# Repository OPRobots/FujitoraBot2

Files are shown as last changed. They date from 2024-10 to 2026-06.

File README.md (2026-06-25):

# FujitoraBot2

Versión 2 de FujitoraBot renovando el hardware después de 5 años: un pelín más
rápido, con 24 sensores de línea, giroscopio MPU-6500 y diseño más modular.

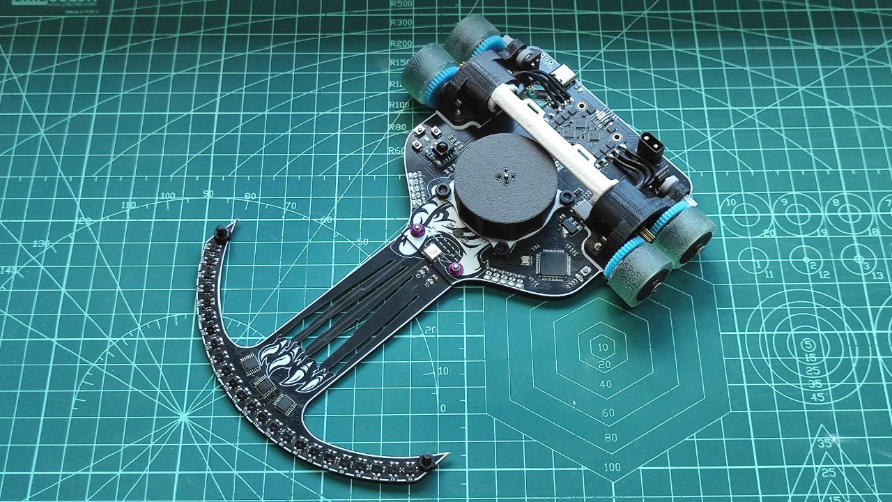
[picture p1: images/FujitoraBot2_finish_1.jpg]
FujitoraBot2


## 🏆 Palmarés

| Competición | Resultado | Fecha |
|---|---|---|
| — | — | — |

## ⚙️ Hardware

| Componente | Detalle |
|---|---|
| **Microcontrolador** | STM32F405RGT6 @ 168 MHz, Cortex-M4F |
| **Sensores** | 24× IR de línea (multiplexados 3×8:1), MPU-6500 (giro ±2000 dps, SPI) |
| **Motores** | 2× DC brushless con ESC BLHeli (OneShot125) |
| **Encoders** | 2× magnéticos en cuadratura (TIM3/TIM4) |
| **Batería** | LiPo 2S/3S, detección automática, divisor ×3.8673 |
| **Ventilador** | Control PWM independiente con rampa de aceleración |
| **Chasis** | PCB propia (KiCad) + impresión 3D |
| **Peso** | — |

## 💻 Software

| Componente | Detalle |
|---|---|
| **Framework** | LibOpenCM3 |
| **Entorno** | PlatformIO |
| **Lenguaje** | C11 |
| **Frecuencia control** | 1000 Hz (TIM5) |
| **Algoritmo** | PID en cascada (velocidad + ángulo + sensores de línea) |
| **Odometría** | Encoders + giroscopio, integración de posición X/Y/θ |
| **Debug** | USART3 @ 115200 + MacroArray (30k registros de telemetría) |

## 📚 Documentación

La documentación técnica completa está en [docs/](docs/):

- [Hardware](docs/01-hardware.md) — MCU, pinout, sensores, actuadores, chasis
- [Arquitectura Software](docs/02-software-architecture.md) — ISRs, DMA, prioridades, flujo
- [Sensores](docs/03-sensors.md) — 24 IR multiplexados, MPU-6500, filtros
- [Movimiento](docs/04-movement.md) — Motores BLHeli, OneShot125, ventilador
- [Control PID](docs/05-control-system.md) — PID cascada, ant-windup, arranque
- [Menú](docs/06-menu-system.md) — Navegación, perfiles, calibración/debug
- [Debug](docs/07-debug-system.md) — USART, macroarray, modos de diagnóstico
- [Calibración](docs/08-calibration.md) — Giroscopio Z, sensores IR, EEPROM
- [EEPROM](docs/09-storage.md) — Flash sector 11, layout de datos
- [Encoders y Giroscopio](docs/10-encoders-gyro.md) — Odometría, MPU-6500, fusión
- [Batería y LEDs](docs/11-battery-leds.md) — Medición, 2S/3S, indicadores
- [Cinemática](docs/12-kinematics.md) — 6 perfiles de velocidad predefinidos
- [Problemas Conocidos](docs/13-known-issues.md) — Issues y bugs documentados

## 🎥 Vídeos

<!-- Enlaces a vídeos del robot en acción -->

## 🔧 Stack Tecnológico

| Herramienta | Tecnología |
|---|---|
| **Microcontrolador** | STM32F405RGT6 |
| **Framework** | LibOpenCM3 |
| **IDE / Build** | PlatformIO |
| **Lenguaje** | C11 |
| **PCB** | KiCad |
| **3D** | SketchUp + STL |

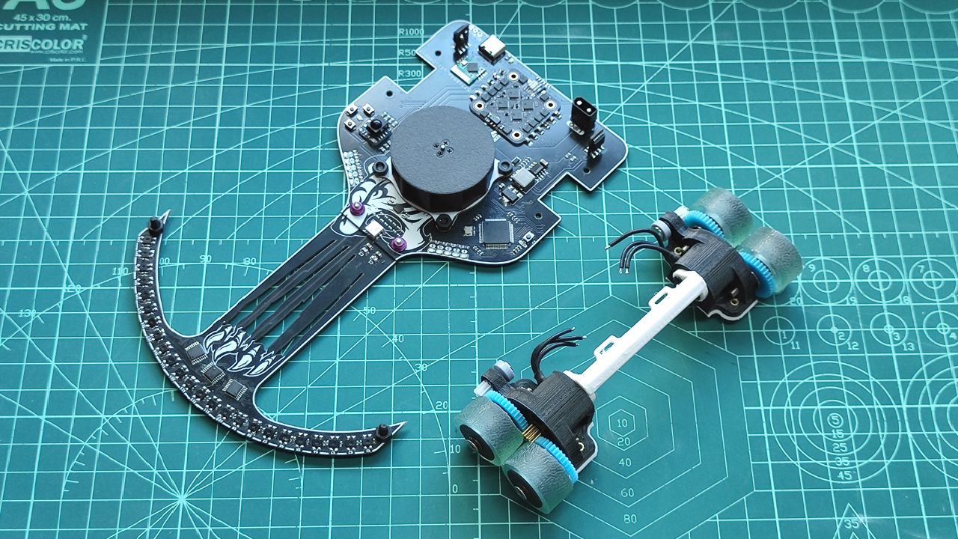
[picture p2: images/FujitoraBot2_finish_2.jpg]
FujitoraBot2


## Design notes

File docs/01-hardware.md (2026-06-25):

# Hardware

## Microcontrolador

| Característica | Detalle |
|---|---|
| **Modelo** | STM32F405RGT6 |
| **Arquitectura** | ARM Cortex-M4F |
| **Frecuencia** | 168 MHz (SYSCLK) |
| **Flash** | 1024 KB |
| **RAM** | 192 KB |
| **Encapsulado** | LQFP-64 |

El reloj principal se genera a partir del HSE de 8 MHz con PLL hasta 168 MHz
([`setup.c:15`](../source_code/src/setup.c#L15)).

## Placa base

Diseño propio en KiCad con dos variantes:

- **Main** — placa principal con MCU, drivers de motor, MPU, y conectores
- **Sensors 24** — placa frontal con 24 sensores IR y multiplexores

Ambos diseños están disponibles en [`pcb_files/kicad_project/`](../pcb_files/kicad_project/).

## Pinout

### GPIOA

| Pin | Función | AF | Descripción |
|-----|---|----|---|
| PA0–PA7 | GPIO Output | — | LEDs de info (menú) |
| PA8–PA11 | AF1 (TIM1) | 1 | PWM LEDs RGB |
| PA15 | GPIO Output | — | CS del MPU (NSS software) |

### GPIOB

| Pin | Función | AF | Descripción |
|-----|---|----|---|
| PB4–PB7 | AF2 (TIM3/4) | 2 | Encoders en cuadratura |
| PB10–PB11 | AF7 (USART3) | 7 | UART debug |
| PB12–PB15 | GPIO Input | — | Botones de menú + IR start |

### GPIOC

| Pin | Función | AF | Descripción |
|-----|---|----|---|
| PC0–PC3 | ADC1 (IN10–IN12) | — | Sensores de línea (3 canales ADC) |
| PC4–PC5 | GPIO Output | — | LEDs de info adicionales |
| PC6–PC9 | AF3 (TIM8) | 3 | PWM motores + ventilador |
| PC10–PC12 | AF6 (SPI3) | 6 | SPI para MPU-6500 |
| PC13–PC15 | GPIO Output | — | Multiplexor de sensores (A/B/C) |

## Sensores

| Característica | Detalle |
|---|---|
| **Sensores de línea** | 24 pares IR (emisor + fototransistor) |
| **Multiplexado** | 3× multiplexores 8:1 → 3 canales ADC (PC0/PC1/PC2) |
| **Giroscopio** | MPU-6500 vía SPI3, ±2000 dps |

(ver [Sensores](03-sensors.md))

## Actuadores

| Componente | Control | Detalle |
|---|---|---|
| **Motor izquierdo** | TIM8 CH1 (PC6) | PWM OneShot125, ESC BLHeli |
| **Motor derecho** | TIM8 CH3 (PC8) | PWM OneShot125, ESC BLHeli |
| **Ventilador** | TIM8 CH2+CH4 (PC7+PC9) | PWM, velocidad configurable por perfil |

(ver [Movimiento](04-movement.md))

## Alimentación

| Característica | Detalle |
|---|---|
| **Batería** | LiPo 2S (7.4 V) o 3S (11.1 V) |
| **Detección** | Automática por rango de tensión |
| **Medición** | ADC2 (PC3/IN13) con divisor ×3.8673 |
| **Límites** | 2S: 7.4–8.2 V / 3S: 11.1–12.6 V |

(ver [Batería y LEDs](11-battery-leds.md))

## Chasis

| Componente | Material | Diseño |
|---|---|---|
| **Chasis principal** | Impresión 3D & PCB | [`3d_model/stl_files/`](../3d_model/stl_files/) |
| **Soporte sensores** | PCB dedicada (sensors_24) | [`pcb_files/kicad_project/sensors_24/`](../pcb_files/kicad_project/sensors_24/) |
| **Ruedas** | — | Control diferencial, separación 0.12 m |

---

*Documento generado el 2026-06-25. Ver también [Arquitectura Software](02-software-architecture.md), [Sensores](03-sensors.md).*

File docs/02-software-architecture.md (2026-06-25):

# Arquitectura Software

## Visión general

El firmware de FujitoraBot2 corre sobre STM32F405RGT6 con LibOpenCM3. Sigue un
modelo baremetal con interrupciones jerarquizadas: el SysTick a 1 kHz orquesta
las lecturas de sensores y encoders, mientras que un timer de alta prioridad
(TIM5) ejecuta el lazo de control a 1 kHz.

## Flujo principal

```mermaid
flowchart TD
    A[main] --> B[setup]
    B --> C[show_battery_level]
    C --> D[eeprom_load]
    D --> E[sensors_calibration]
    E --> F{race_started?}
    F -->|No| G[menu_handler]
    G --> H{check_start_run?}
    H -->|Sí| I[Configurar cinemática]
    I --> J[Cuenta atrás + fade RGB]
    J --> K[Arrancar motores]
    K --> F
    H -->|No| F
    F -->|Sí| L{IR start off?}
    L -->|Sí| M[emergency_stop]
    L -->|No| F
```

## Mapa de interrupciones

| IRQ | Prioridad | Handler | Función |
|-----|---|---|---|
| **SysTick** | 0 (máx) | `sys_tick_handler` | Clock tick, encoders, ESC init, botones, sensores, giro, batería |
| **DMA2 Stream0** | 1 | `dma2_stream0_isr` | Lectura DMA de ADC1 → actualización multiplexor |
| **TIM2** | 2 | — | Captura encoder derecho |
| **TIM5** | 3 | `tim5_isr` | Lazo de control PID @ 1 kHz |
| **USART3** | 4 | — | Recepción UART (no crítica) |

Las prioridades están definidas en [`setup.c:52-63`](../source_code/src/setup.c#L52-L63).
La prioridad 0 es la más alta en el esquema NVIC de Cortex-M4 (16 grupos).

## SysTick (1 kHz)

El `sys_tick_handler` en [`main.c:19-27`](../source_code/src/main.c#L19-L27) ejecuta
cada milisegundo:

1. `clock_tick()` — incrementa el contador de tiempo del sistema
2. `update_encoder_readings()` — lee encoders en cuadratura y calcula odometría
3. `init_esc()` — secuencia de inicialización de los ESCs (5 s de pulso neutro)
4. `check_buttons()` — lee los botones físicos
5. `sensors_update_line_position()` — calcula la posición de la línea
6. `update_gyro_readings()` — lee el giroscopio y actualiza el ángulo integrado
7. `update_battery_voltage()` — lee y filtra la tensión de batería

## Lazo de control (TIM5, ~1 kHz)

El `tim5_isr` en [`setup.c:247-251`](../source_code/src/setup.c#L247-L251) invoca
`control_loop()` que implementa el control PID en cascada:

```mermaid
flowchart TD
    A[control_loop] --> B{race_started?}
    B -->|No| C[Parar motores + fan]
    B -->|Sí| D[update_ideal_linear_speed]
    D --> E[update_fan_speed]
    E --> F{control_strategy}
    F -->|ENCODERS| G[PID velocidad lineal]
    F -->|PWM| H[% PWM directo]
    G --> I[Cálculo corrección angular]
    H --> I
    I --> J[PID angular + sensores línea]
    J --> K[Conversión voltaje → PWM]
    K --> L[set_motors_pwm + set_fan_speed]
    L --> M[macroarray_store]
```

(ver [Control PID](05-control-system.md))

## ADC y DMA

El ADC1 lee 3 canales en modo scan continuo con DMA circular (DMA2 Stream0):

- **Canal 10 (PC0)**: multiplexor 8:1, sensores 0–7
- **Canal 11 (PC1)**: multiplexor 8:1, sensores 8–15
- **Canal 12 (PC2)**: multiplexor 8:1, sensores 16–23

Cada vez que el DMA completa una transferencia (3 lecturas), la ISR
`sensors_update_mux_readings()` asigna las lecturas al slot correcto del array
de 24 sensores y avanza el multiplexor.

## Máquina de estados del menú

```mermaid
stateDiagram-v2
    [*] --> MenuRun
    MenuRun --> MenuConfig : pulsación larga mode
    MenuConfig --> MenuRun : pulsación larga mode

    state MenuRun {
        [*] --> SpeedSelect
        SpeedSelect --> RaceMode : mode btn
        RaceMode --> Adaptative : mode btn
        Adaptative --> BiggerFilter : mode btn
        BiggerFilter --> DigitalSensors : mode btn
        DigitalSensors --> Encoders : mode btn
        Encoders --> SpeedSelect : mode btn
    }

    state MenuConfig {
        [*] --> Calibration
        Calibration --> Debug : mode btn
        Debug --> Calibration : mode btn
    }
```

(ver [Menú](06-menu-system.md))

## Módulos del proyecto

| Módulo | Archivos | Descripción |
|---|---|---|
| **setup** | `setup.c/h` | Configuración de relojes, GPIO, timers, ADC, SPI, DMA |
| **control** | `control.c/h` | Lazo PID, arranque/parada, gestión de carrera |
| **sensors** | `sensors.c/h` | Lectura y calibración de 24 sensores de línea |
| **motors** | `motors.c/h` | Control PWM de motores y ventilador |
| **encoders** | `encoders.c/h` | Odometría y velocidades |
| **mpu** | `mpu.c/h` | Giroscopio MPU-6500 vía SPI |
| **menu** | `menu.c/h` | Sistema de menú principal |
| **menu_run** | `menu_run.c/h` | Menú de selección de modos de carrera |
| **menu_configs** | `menu_configs.c/h` | Menú de calibración y debug |
| **kinematics** | `kinematics.c/h` | Perfiles de velocidad predefinidos |
| **battery** | `battery.c/h` | Medición de batería |
| **leds** | `leds.c/h` | Control de LEDs (estado, RGB, info) |
| **eeprom** | `eeprom.c/h` | EEPROM emulada en flash |
| **debug** | `debug.c/h` | Sistema de debug y telemetría |
| **macroarray** | `macroarray.c/h` | Buffer de logging para análisis post-carrera |
| **delay** | `delay.c/h` | Utilidades de tiempo (ms, us, DWT) |
| **utils** | `utils.c/h` | `map()` y `constrain()` |
| **buttons** | `buttons.c/h` | Lectura de botones e IR start |
| **usart** | `usart.c/h` | Redirección de `printf` a USART3 |

---

*Documento generado el 2026-06-25. Ver también [Hardware](01-hardware.md), [Control PID](05-control-system.md).*

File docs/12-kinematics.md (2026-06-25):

# Cinemática

FujitoraBot2 define 6 perfiles de velocidad preconfigurados que controlan
la velocidad lineal máxima, las rampas de aceleración/frenado y la velocidad
del ventilador.

## Perfiles de velocidad

| Perfil | Velocidad (mm/s) | Acel. (mm/s²) | Frenada (mm/s²) | PWM (%) | Ventilador |
|---|---|---|---|---|---|
| **TEST** | 2000 | 10000 | 5000 | 27% | 20% |
| **BASE** | 2500 | 10000 | 10000 | 33% | 30% |
| **NORMAL** | 3000 | 10000 | 10000 | 40% | 40% |
| **MEDIUM** | 3500 | 20000 | 20000 | 50% | 50% |
| **FAST** | 4000 | 20000 | 20000 | 60% | 60% |
| **HAKI** | 4500 | 20000 | 20000 | 70% | 75% |

Definidos en [`kinematics.c:3-57`](../source_code/src/kinematics.c#L3-L57).

## Estructura `kinematics`

Cada perfil contiene:

| Campo | Tipo | Descripción |
|---|---|---|
| `linear_speed` | `int16_t` | Velocidad lineal objetivo (mm/s) |
| `linear_accel` | `int16_t` | Aceleración lineal (mm/s²) |
| `linear_break` | `int16_t` | Deceleración lineal (mm/s²) |
| `linear_speed_percent` | `int16_t` | % PWM en modo CONTROL_PWM |
| `linear_accel_percent` | `int16_t` | Aceleración en modo PWM (%/s) |
| `linear_break_percent` | `int16_t` | Deceleración en modo PWM (%/s) |
| `fan_speed` | `int16_t` | Velocidad del ventilador (0–100) |

## Rampas de velocidad

La velocidad ideal sigue una rampa lineal gobernada por los parámetros de
aceleración y frenada:

```
Modo ENCODERS:
  si ideal < target → ideal += linear_accel / 1000  (cada ms)
  si ideal > target → ideal -= linear_break / 1000

Modo PWM:
  si ideal_pct < target_pct → ideal_pct += linear_accel_percent / 1000
  si ideal_pct > target_pct → ideal_pct -= linear_break_percent / 1000
```

La frecuencia de actualización es 1 kHz, por lo que la aceleración expresada
en mm/s² se divide entre 1000.

### Ejemplo: perfil FAST

Arranque en modo encoder de 0 a 4000 mm/s:
- Incremento por tick: 20000 / 1000 = 20 mm/s por ms
- Tiempo hasta velocidad objetivo: 4000 / 20 = 200 ms

## Ventilador

La velocidad del ventilador sigue su propia rampa independiente:

```
aceleración_fan = (target − actual) × 1000 / ms_transición
```

Al iniciar la carrera, el ventilador arranca al 75% de la cuenta atrás (si
`fan_speed > 0` en el perfil) a la mitad de la velocidad objetivo configurada.

Tras la carrera, el ventilador se detiene 500 ms después del `emergency_stop`
o la finalización normal.

## Selección de perfil

El perfil se selecciona desde el menú Run → Speed. El valor se carga en
`configure_kinematics()` al iniciar la carrera:

```c
configure_kinematics(menu_run_get_speed());
set_target_linear_speed(get_kinematics().linear_speed);
set_target_linear_speed_percent(get_kinematics().linear_speed_percent);
set_target_fan_speed(get_kinematics().fan_speed, 500);
```

## Modo de control

El perfil define valores tanto para el control por encoders como por PWM.
El modo activo se selecciona en el menú Run → Encoders:

- **Encoders ON** (`CONTROL_ENCODERS`): usa `linear_speed`, `linear_accel`, `linear_break`
- **Encoders OFF** (`CONTROL_PWM`): usa `linear_speed_percent`, `linear_accel_percent`, `linear_break_percent`

(ver [Control PID](05-control-system.md))

---

*Documento generado el 2026-06-25. Ver también [Control PID](05-control-system.md), [Movimiento](04-movement.md), [Menú](06-menu-system.md).*

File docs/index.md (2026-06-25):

# FujitoraBot2

Versión 2 de FujitoraBot, renovando el hardware después de 5 años: más rápido,
con 24 sensores de línea, giroscopio MPU-6500 y diseño más modular. Robot
micromouse de competición orientado al seguimiento de línea de alta velocidad.

FujitoraBot2

## 🏆 Palmarés

| Competición | Resultado | Fecha |
|---|---|---|
| — | — | — |

---

## ⚙️ Hardware

| Característica | Detalle |
|---|---|
| **Microcontrolador** | STM32F405RGT6 @ 168 MHz |
| **Sensores** | 24 sensores IR de línea + MPU-6500 (giroscopio 3 ejes) |
| **Motores** | 2× DC con ESC BLHeli (OneShot125) + ventilador |
| **Encoders** | 2× encoders magnéticos en cuadratura |
| **Batería** | LiPo 2S/3S con divisor de tensión y detección automática |
| **Chasis** | Diseño propio en 3D (SketchUp + STL) + PCB KiCad |

---

## 💻 Software

| Componente | Detalle |
|---|---|
| **Framework** | LibOpenCM3 |
| **Frecuencia control** | 1000 Hz (TIM5) |
| **Algoritmo** | PID en cascada: velocidad lineal + corrección angular (giro + sensores) |
| **Debug** | USART3 @ 115200 baud + MacroArray para telemetría |

---

## 📚 Documentación

- [Hardware](01-hardware.md)
- [Arquitectura Software](02-software-architecture.md)
- [Sensores](03-sensors.md)
- [Movimiento](04-movement.md)
- [Control PID](05-control-system.md)
- [Menú](06-menu-system.md)
- [Debug](07-debug-system.md)
- [Calibración](08-calibration.md)
- [EEPROM](09-storage.md)
- [Encoders y Giroscopio](10-encoders-gyro.md)
- [Batería y LEDs](11-battery-leds.md)
- [Cinemática](12-kinematics.md)
- [Problemas Conocidos](13-known-issues.md)

---

## 🔧 Stack Tecnológico

| Componente | Detalle |
|---|---|
| **MCU** | STM32F405RGT6 @ 168 MHz (ARM Cortex-M4F) |
| **Framework** | LibOpenCM3 + PlatformIO |
| **Lenguaje** | C11 |
| **Compilador** | GCC ARM Embedded (arm-none-eabi-gcc) |
| **IDE** | VSCode |

---

## 🎥 Vídeos

<!-- Enlaces a vídeos del robot en acción -->

*Documento generado el 2026-06-25. Ver también [Hardware](01-hardware.md).*

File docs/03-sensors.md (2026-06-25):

# Sensores

FujitoraBot2 usa 24 sensores IR de línea multiplexados en 3 canales ADC del
STM32F405, más un giroscopio MPU-6500 para corrección angular.

## Sensores de línea

### Arquitectura

24 pares emisor-receptor IR están distribuidos linealmente en la PCB frontal
`sensors_24`. Se leen mediante 3 multiplexores analógicos 8:1 controlados por
los pines PC13 (A), PC14 (B) y PC15 (C):

| Canal ADC | Pin STM32 | Multiplexor | Sensores |
|---|---|---|---|
| ADC1 IN10 | PC0 | MUX 1 | 8–15 |
| ADC1 IN11 | PC1 | MUX 2 | 0–7 |
| ADC1 IN12 | PC2 | MUX 3 | 16–23 |

> **💡 Consejo**: Los canales ADC están mapeados de forma no secuencial.
> El canal 10 corresponde a los sensores 8–15, no a los primeros. Ver
> [`sensors.c:4`](../source_code/src/sensors.c#L4) y la nota en
> [`sensors.c:217-218`](../source_code/src/sensors.c#L217-L218) sobre
> desorden de canales al activar ADC2.

### Lectura con DMA

El ADC1 opera en modo scan continuo con DMA circular (DMA2 Stream0). Cada
transferencia completa dispara `sensors_update_mux_readings()` que:

1. Asigna las 3 lecturas ADC al slot correspondiente del array `sensors_raw[24]`
2. Avanza el índice del multiplexor (0→7)
3. Actualiza los pines A/B/C del mux para la siguiente ronda
4. Espera 3 µs de settling time

La tasa de muestreo efectiva es de aproximadamente 1 kHz por sensor (8 slots × 3
canales = 24 lecturas por ciclo completo DMA).

### Calibración

Cada sensor tiene tres valores almacenados en EEPROM:

| Parámetro | Significado |
|---|---|
| `sensors_min` | Lectura ADC sobre superficie blanca (mínima reflectividad) |
| `sensors_max` | Lectura ADC sobre línea negra (máxima reflectividad) |
| `sensors_umb` | Umbral de detección = min + (max − min) × 2/3 |

(ver [Calibración](08-calibration.md))

### Modos de funcionamiento

| Modo | Enum | Comportamiento |
|---|---|---|
| **Analógico** | `SENSORS_ANALOG` | Valores crudos dentro del 20%–80% del rango de calibración; el resto se satura |
| **Digital** | `SENSORS_DIGITAL` | Binario: supera o no el umbral `sensors_umb` |

Configurado desde el menú de carrera ([`menu_run.c`](../source_code/src/menu_run.c)).

### Filtro BiggerFilter

Cuando `FILTER_BIGGER` está activo, solo los 4 sensores alrededor de la
posición estimada de la línea contribuyen al cálculo de posición. El resto
se fuerzan a 0.

Esto reduce el ruido de sensores lejanos que aún detectan la línea en curvas
cerradas o cuando el robot está descentrado, mejorando la precisión de la
estimación de posición a alta velocidad.

### Cálculo de posición de línea

El algoritmo en [`sensors.c:262-331`](../source_code/src/sensors.c#L262-L331):

1. **Ventana de búsqueda**: se reduce a los 4 sensores alrededor de la última
   posición conocida
2. **Media ponderada**: cada sensor contribuye proporcionalmente a su lectura:
   ```
   posición = Σ(sensor_i × valor_i × 1000) / Σ(valor_i) − offset_central
   ```
3. **Normalización**: resultado mapeado al rango [−1000, +1000]
4. **Detección de pérdida**: si ningún sensor supera el umbral durante
   `TIEMPO_SIN_PISTA` ms (150 ms por defecto), se activa la parada de emergencia

### Detección de fuera de pista

Si la mitad o más de los sensores detectan línea simultáneamente, se considera
ruido (robot completamente fuera del circuito) y se ignora el evento. En caso
contrario, se actualiza un timestamp (`ultimaLinea`). Si pasa demasiado tiempo
sin detectar línea, se ejecuta `emergency_stop()`.

## Giroscopio MPU-6500

| Característica | Detalle |
|---|---|
| **Modelo** | MPU-6500 (InvenSense/TDK) |
| **Interfaz** | SPI3 (PC10–PC12, NSS en PA15) |
| **Rango** | ±2000 dps |
| **Sensibilidad** | 16.4 LSB/dps |
| **Filtro** | DLPF 250 Hz |
| **Sample rate** | 8 kHz interno (SMPLRT_DIV = 0) |
| **Calibración** | Offset en registro MPU + soft integración |

(ver [Encoders y Giroscopio](10-encoders-gyro.md))

---

*Documento generado el 2026-06-25. Ver también [Hardware](01-hardware.md), [Calibración](08-calibration.md), [Encoders y Giroscopio](10-encoders-gyro.md).*

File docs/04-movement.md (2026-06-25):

# Movimiento

## Motores DC

FujitoraBot2 usa dos motores DC brushless con controladores ESC compatibles con
el protocolo **OneShot125** (PWM de 125–250 µs de pulso), más un ventilador de
refrigeración controlado por PWM.

| Característica | Detalle |
|---|---|
| **Tipo** | DC brushless con ESC |
| **Protocolo** | OneShot125 (PWM 4 kHz, resolución 1024 pasos) |
| **Timer PWM** | TIM8, canales 1–4 |
| **Frecuencia PWM** | 4 kHz |
| **Pulso neutro** | MOTORS_STOP_PWM = 512 |
| **Pulso máximo** | MOTORS_MAX_PWM = 1024 |

## Control PWM

### Timer y canales

| Canal TIM8 | Pin | Función |
|---|-----|---|
| CH1 | PC6 | Motor izquierdo |
| CH2 | PC7 | Ventilador (canal A) |
| CH3 | PC8 | Motor derecho |
| CH4 | PC9 | Ventilador (canal B) |

El timer se configura en [`setup.c:214-233`](../source_code/src/setup.c#L214-L233).

### Inicialización de ESCs

Al arrancar, los ESCs requieren una secuencia de inicialización de 5 segundos
con pulso neutro (`MOTORS_STOP_PWM = 512`) antes de aceptar comandos. Esto se
gestiona en `init_esc()` ([`motors.c:10-28`](../source_code/src/motors.c#L10-L28)):

1. Se habilita la salida de los 4 canales TIM8
2. Durante 5 s se mantiene el pulso en `MOTORS_STOP_PWM`
3. Transcurrido ese tiempo, `escInited = true` y se aceptan comandos

### Conversión velocidad → PWM

Hay dos modos de control de velocidad lineal (ver [Control PID](05-control-system.md)):

1. **Modo encoder** (`CONTROL_ENCODERS`): el lazo PID calcula un voltaje lineal
   que se convierte a PWM:
   ```
   pwm = MOTORS_STOP_PWM + (voltaje / V_batería) × (MOTORS_MAX_PWM / 2)
   ```

2. **Modo PWM** (`CONTROL_PWM`): se aplica un porcentaje directo de PWM sobre
   la tensión nominal de batería.

En ambos modos, la corrección angular (diferencial) se suma al PWM de una rueda
y se resta de la otra:

```
pwm_left  = MOTORS_STOP_PWM + voltage_to_pwm(linear_voltage + angular_voltage)
pwm_right = MOTORS_STOP_PWM + voltage_to_pwm(linear_voltage - angular_voltage)
```

### Zona muerta y límites

- **PWM mínimo**: `MOTORS_MIN_PWM = 522` (≈2% por encima del neutro) para
  evitar el *cogging* del motor a bajas revoluciones
- **Velocidad mínima inicial**: 165 (valor empírico calculado en
  [`control.c:214`](../source_code/src/control.c#L214))
- **PWM máximo**: 1024 (saturación por hardware)

### Parada de emergencia

`emergency_stop()` detiene inmediatamente los motores poniendo PWM neutro y
desactiva el modo carrera. Se dispara por:

- Pérdida de señal IR (fin de carrera o desconexión)
- Pérdida de línea durante más de `TIEMPO_SIN_PISTA` ms

(ver [Control PID](05-control-system.md#parada-de-emergencia))

## Ventilador

| Característica | Detalle |
|---|---|
| **Control** | TIM8 CH2 + CH4 |
| **Velocidad** | 0–100 (mapeado a PWM) |
| **Rampa** | Aceleración configurable por perfil de velocidad |
| **Inicio** | Arranca al 75% de la cuenta atrás si `fan_speed > 0` |
| **Parada** | Se apaga 500 ms después de terminar la carrera |

La velocidad objetivo y la rampa de aceleración se configuran en el perfil
cinemático seleccionado.

(ver [Cinemática](12-kinematics.md))

---

*Documento generado el 2026-06-25. Ver también [Control PID](05-control-system.md), [Cinemática](12-kinematics.md).*

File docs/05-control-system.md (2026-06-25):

# Control PID

El sistema de control de FujitoraBot2 implementa un PID en cascada que regula
la velocidad lineal y la corrección angular de forma independiente. El lazo
se ejecuta a 1 kHz mediante la interrupción de TIM5.

## Arquitectura del lazo

```mermaid
flowchart TD
    A[Velocidad lineal objetivo] --> B[Rampa aceleración]
    B --> C{Control Strategy}
    C -->|ENCODERS| D[PID velocidad lineal]
    C -->|PWM| E[% PWM directo]
    D --> F[Voltaje lineal]
    E --> F

    G[Velocidad angular objetivo = 0] --> H[PID angular con MPU]
    I[Posición de línea] --> J[PID sensores de línea]
    H --> K[Voltaje angular]
    J --> K

    F --> L[voltaje_left = V_linear + V_angular]
    F --> M[voltaje_right = V_linear - V_angular]
    K --> L
    K --> M
    L --> N[Convertir voltaje → PWM]
    M --> N
    N --> O[Motores]
```

## Control de velocidad lineal

### Modo Encoder (CONTROL_ENCODERS)

Control proporcional-derivativo sobre el error de velocidad medido por los
encoders:

```
error = Σ(velocidad_ideal − velocidad_medida)
V_linear = KP_LINEAR × error + KD_LINEAR × (error − last_error)
```

| Parámetro | Valor | Descripción |
|---|---|---|
| `KP_LINEAR` | 0.00025 | Ganancia proporcional |
| `KD_LINEAR` | 0.0 | Ganancia derivativa (desactivada) |

> **⚠️ Advertencia**: `KD_LINEAR` está a 0.0 en la configuración actual. El
> control de velocidad lineal es puramente integral (I).

**Anti-windup**: si el error acumulado supera 8000 y la velocidad medida es
inferior a 1000 mm/s, el error se satura a 8000 para evitar que la integral
crezca descontroladamente durante la aceleración inicial
([`control.c:254-256`](../source_code/src/control.c#L254-L256)).

### Modo PWM (CONTROL_PWM)

Control en lazo abierto: se aplica un porcentaje fijo de la tensión de batería:

```
V_linear = V_batería_nominal × porcentaje / 100
```

Útil para pruebas y diagnóstico cuando los encoders no están disponibles.

### Rampa de aceleración

La velocidad ideal sigue una rampa lineal hasta alcanzar la velocidad objetivo,
controlada por los parámetros `linear_accel` y `linear_break` del perfil
cinemático activo:

```
si ideal < target: ideal += linear_accel / 1000
si ideal > target: ideal -= linear_break / 1000
```

(ver [Cinemática](12-kinematics.md))

## Corrección angular

La corrección angular combina dos fuentes:

### PID sobre giroscopio (MPU)

Corrige la velocidad angular para mantener trayectoria recta (velocidad angular
objetivo = 0):

```
angular_error = Σ(0 − velocidad_angular_medida)
V_angular_gyro = KP_ANGULAR × angular_error + KD_ANGULAR × Δangular_error
```

| Parámetro | Valor | Descripción |
|---|---|---|
| `KP_ANGULAR` | 0.04 | Ganancia proporcional angular |
| `KD_ANGULAR` | 0.3 | Ganancia derivativa angular |

### PID sobre sensores de línea

Corrige la posición lateral respecto a la línea:

```
V_angular_line = KP_LINE_SENSORS × posición + KI_LINE_SENSORS × Σposición + KD_LINE_SENSORS × Δposición
```

| Parámetro | Valor | Descripción |
|---|---|---|
| `KP_LINE_SENSORS` | 0.008 | Ganancia proporcional de línea |
| `KI_LINE_SENSORS` | 0.0 | Ganancia integral de línea (desactivada) |
| `KD_LINE_SENSORS` | 0.10 | Ganancia derivativa de línea |

### Activación de correcciones

Las correcciones se activan secuencialmente al iniciar la carrera:

1. **Inicio**: solo corrección por sensores de línea (`line_sensors_correction_enabled = true`)
2. **Corrección MPU**: se activa por separado cuando se requiere (`mpu_correction_enabled = true`)

Ambas pueden habilitarse/deshabilitarse independientemente durante la carrera.

## Conversión voltaje → PWM

```c
pwm = MOTORS_STOP_PWM + (voltaje / V_batería) × (MOTORS_MAX_PWM / 2)
```

La conversión compensa la tensión de batería para mantener la misma velocidad
independientemente del nivel de carga.

| Constante | Valor | Descripción |
|---|---|---|
| `MOTORS_STOP_PWM` | 512 | PWM neutro (motor parado) |
| `MOTORS_MAX_PWM` | 1024 | PWM máximo |
| `MOTORS_MIN_PWM` | 522 | PWM mínimo efectivo (evita cogging) |

## Parada de emergencia

La función `emergency_stop()` en [`control.c:347-350`](../source_code/src/control.c#L347-L350):

1. Desactiva `race_started`
2. Registra el timestamp de parada (`emergency_stop_ms`)
3. El lazo de control, al ver `!is_race_started()`, pone PWM neutro en los motores
4. El ventilador se apaga tras 500 ms

Disparadores:
- Señal IR pasa de HIGH a LOW durante la carrera
- Pérdida de línea > `TIEMPO_SIN_PISTA` (150 ms)

## Sistema de arranque

La carrera se inicia mediante:

1. **Señal IR** — flanco ascendente detectado en `check_start_run()`
2. **Botón Mode** — pulsación larga (>1.2 s) como alternativa

Al arrancar:
1. Se configura el perfil cinemático seleccionado en el menú
2. Cuenta atrás configurable (`get_start_millis()`, típicamente 5000 ms)
3. El LED RGB hace un fade de rojo a verde durante la cuenta atrás
4. El ventilador arranca al 75% de la cuenta atrás
5. Al terminar, se activan las correcciones de sensores y los motores

## Telemetría en carrera

Durante la carrera, `control_loop()` almacena en el MacroArray:

| Variable | Descripción |
|---|---|
| `target_linear_speed` | Velocidad objetivo |
| `ideal_linear_speed` | Velocidad ideal (post-rampa) |
| `measured_linear_speed` | Velocidad medida por encoders |
| `line_sensors_error` | Posición de línea (−1000 a +1000) |
| `linear_voltage` | Voltaje lineal aplicado |
| `angular_voltage` | Voltaje angular aplicado |
| `pwm_left/right` | PWM enviado a cada motor |
| `battery_voltage` | Tensión de batería |

(ver [Debug](07-debug-system.md))

---

*Documento generado el 2026-06-25. Ver también [Sensores](03-sensors.md), [Movimiento](04-movement.md), [Cinemática](12-kinematics.md).*

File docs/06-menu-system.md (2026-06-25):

# Menú

FujitoraBot2 implementa un sistema de menú con dos niveles principales y
retroalimentación visual mediante LEDs. La navegación se realiza con tres
botones físicos.

## Botones

| Botón | Pin | Función |
|---|-----|---|
| **IR Start** | PB12 | Sensor IR remoto para inicio de carrera |
| **Menu Up** | PB13 | Incrementar valor / opción anterior |
| **Menu Down** | PB14 | Decrementar valor / opción siguiente |
| **Menu Mode** | PB15 | Cambiar modo / pulsación larga para volver |

Los botones se leen en `check_buttons()` llamado desde el SysTick a 1 kHz.

## Estructura del menú

```mermaid
stateDiagram-v2
    [*] --> MenuRun
    MenuRun --> MenuConfig : pulsación larga mode
    MenuConfig --> MenuRun : pulsación larga mode

    state MenuRun {
        SPEED --> RACE : mode
        RACE --> ADAPTATIVE : mode
        ADAPTATIVE --> BIGGER_FILTER : mode
        BIGGER_FILTER --> DIGITAL_SENSORS : mode
        DIGITAL_SENSORS --> ENCODERS : mode
        ENCODERS --> SPEED : mode
    }

    state MenuConfig {
        CALIBRATION --> DEBUG : mode
        DEBUG --> CALIBRATION : mode
    }
```

## Menú Run — selección de modo de carrera

El menú principal (por defecto al encender) permite configurar los parámetros
de la carrera. Tiene 6 modos:

| Modo | Variable | Opciones |
|---|---|---|
| **Speed** | `valueRun[0]` | TEST, BASE, NORMAL, MEDIUM, FAST, HAKI |
| **Race** | `valueRun[1]` | 0 = Standby, 1 = Preparado |
| **Adaptative** | `valueRun[2]` | 0 = No, 1 = Sí |
| **BiggerFilter** | `valueRun[3]` | 0 = No, 1 = Sí |
| **Digital Sensors** | `valueRun[4]` | 0 = Analógico, 1 = Digital |
| **Encoders** | `valueRun[5]` | 0 = PWM, 1 = Encoders |

Los valores se guardan en EEPROM al activar el modo carrera (`valueRun[1] = 1`).

### Perfiles de velocidad

| Perfil | Índice | Descripción |
|---|---|---|
| `SPEED_TEST` | 0 | 2000 mm/s — pruebas lentas |
| `SPEED_BASE` | 1 | 2500 mm/s — base de desarrollo |
| `SPEED_NORMAL` | 2 | 3000 mm/s — velocidad normal |
| `SPEED_MEDIUM` | 3 | 3500 mm/s — velocidad media |
| `SPEED_FAST` | 4 | 4000 mm/s — alta velocidad |
| `SPEED_HAKI` | 5 | 4500 mm/s — velocidad máxima |

### Indicadores LED

- **LEDs de info 0–4**: barra de velocidad seleccionada (SPEED_TEST = LED0,
  SPEED_HAKI = todos encendidos parpadeando)
- **LED de info 5**: velocidad adaptativa activa
- **LED de info 6**: BiggerFilter activo
- **LED de info 8**: sensores digitales activos
- **LED de info 9**: control por encoders activo
- **LED RGB**: verde si el modo está activo; morado si Race Mode está armado

## Menú Config — calibración y debug

Accesible con pulsación larga (>200 ms) del botón Mode desde el menú Run.

| Modo | Opciones |
|---|---|
| **Calibration** | None, Calibrate Gyro Z, Calibrate Sensors, Store EEPROM |
| **Debug** | None, MacroArray, Sensors Raw, Sensors Calibrated, Line Position, Motors, Encoders, Digital IO, Position Correction, LED Party, Fan Demo |

### Indicadores LED

- **LED de estado**: parpadeo rápido = modo Calibración; encendido fijo = modo Debug
- **LED RGB**: verde durante calibración activa

(ver [Calibración](08-calibration.md), [Debug](07-debug-system.md))

---

*Documento generado el 2026-06-25. Ver también [Calibración](08-calibration.md), [Debug](07-debug-system.md).*

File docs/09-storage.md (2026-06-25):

# EEPROM

FujitoraBot2 emula una EEPROM usando el sector 11 de la flash interna del
STM32F405 (último sector de 128 KB). Almacena calibraciones y configuración
de menú de forma persistente entre reinicios.

## Configuración de flash

| Característica | Detalle |
|---|---|
| **Sector** | 11 (último sector de 128 KB) |
| **Dirección base** | `0x080E0000` |
| **Tamaño del sector** | 128 KB |
| **Tamaño de palabra** | 16 bits (`FLASH_CR_PROGRAM_X16`) |
| **Operaciones** | Lectura directa (`MMIO32`), escritura (`flash_program_word`), borrado (`flash_erase_sector`) |

> **⚠️ Advertencia**: El borrado de la flash es por sector completo. Cualquier
> escritura requiere borrar las 128 KB del sector 11, lo que bloquea la CPU
> durante la operación. El guardado solo se realiza cuando hay cambios
> (`is_dirty = true`).

## Layout de datos

El array `eeprom_data[]` tiene `DATA_LENGTH` elementos de 16 bits cada uno:

| Offset | Índice | Tamaño | Contenido |
|---|---|---|---|
| `DATA_INDEX_GYRO_Z` | 0 | 1 | Offset Z del giroscopio |
| `DATA_INDEX_SENSORS_MAX` | 1–24 | 24 | Valores máximos de calibración por sensor |
| `DATA_INDEX_SENSORS_MIN` | 25–48 | 24 | Valores mínimos de calibración por sensor |
| `DATA_INDEX_SENSORS_UMB` | 49–72 | 24 | Umbrales de detección por sensor |
| `DATA_INDEX_MENU_RUN` | 73–78 | 6 | Valores del menú de carrera |

Total: 79 palabras de 16 bits = 158 bytes útiles.

## Operaciones

### Carga (`eeprom_load`)

Se ejecuta al inicio de `main()`:

1. Lee todo el sector 11 mediante `MMIO32` palabra a palabra
2. Si el botón Up NO está pulsado: carga el offset del giro y lo aplica al MPU
3. Carga los valores de calibración de sensores
4. Carga los valores del menú de carrera
5. Fuerza `valueRun[MODE_RACE] = 0` para evitar arranque accidental

### Guardado (`eeprom_save`)

1. Verifica que haya cambios pendientes (`is_dirty`)
2. Espera 200 ms con LED de warning
3. Desbloquea la flash
4. Borra el sector 11 completo
5. Escribe las 79 palabras secuencialmente
6. Bloquea la flash

### Marca de suciedad

`eeprom_set_data()` compara los valores nuevos con los existentes. Si algún
valor difiere, activa `is_dirty = true`. Esto evita escrituras innecesarias
que desgastarían la flash.

### Borrado completo

`eeprom_clear()` borra el sector sin reescribir. Útil para resetear a
valores de fábrica.

## Secuencia de inicio

```mermaid
sequenceDiagram
    participant Main
    participant EEPROM
    participant MPU
    participant Sensors
    participant Menu

    Main->>EEPROM: eeprom_load()
    EEPROM->>MPU: mpu_load_eeprom() (si Up no pulsado)
    EEPROM->>Sensors: sensors_load_eeprom()
    EEPROM->>Menu: menu_run_load_values()
    Note over Main: Continúa con calibración y menú
```

---

*Documento generado el 2026-06-25. Ver también [Calibración](08-calibration.md), [Menú](06-menu-system.md).*

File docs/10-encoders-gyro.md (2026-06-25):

# Encoders y Giroscopio

FujitoraBot2 combina dos sistemas de navegación inercial: encoders magnéticos en
cuadratura para odometría y un giroscopio MPU-6500 para medición de velocidad
angular. Ambos se actualizan en el SysTick a 1 kHz.

## Encoders en cuadratura

### Hardware

| Característica | Detalle |
|---|---|
| **Tipo** | Encoders magnéticos en cuadratura |
| **Timer izquierdo** | TIM4 (PB6, PB7) — modo encoder 3 (TI1+TI2) |
| **Timer derecho** | TIM3 (PB4, PB5) — modo encoder 3 (TI1+TI2) |
| **Resolución** | 16 bits (0–65535) |
| **Micrómetros por tick** | 14.5356 µm/tick |

### Configuración

Los timers se configuran en modo *slave encoder 3* (`TIM_SMCR_SMS_EM3`) que
cuenta automáticamente los flancos en ambas señales de cuadratura
([`setup.c:254-266`](../source_code/src/setup.c#L254-L266)).

### Algoritmo de lectura

La función `max_likelihood_counter_diff()` en
[`encoders.c:117-126`](../source_code/src/encoders.c#L117-L126) maneja el
overflow del contador de 16 bits:

- Calcula la diferencia hacia adelante y hacia atrás
- Asume la diferencia más pequeña como la dirección real
- Esto funciona siempre que las lecturas sean más rápidas que medio overflow
  (32768 ticks entre lecturas → suficiente a 1 kHz)

### Variables calculadas

Cada 1 ms, `update_encoder_readings()` actualiza:

| Variable | Unidad | Fórmula |
|---|---|---|
| `left/right_diff_ticks` | ticks | diff desde última lectura |
| `left/right_total_ticks` | ticks | acumulado absoluto |
| `left/right_micrometers` | µm | `total_ticks × 14.5356` |
| `left/right_millimeters` | mm | `micrometers / 1000` |
| `left/right_speed` | mm/s | `diff_ticks × 14.5356/1000 × 1000` |
| `angular_speed` | rad/s | `(speed_L − speed_R) / 1000 / 0.12` |
| `current_angle` | rad | integración de `angular_speed / 1000` |
| `position_x` | mm | integración de velocidad × cos(angle) |
| `position_y` | mm | integración de velocidad × sin(angle) |

> **💡 Consejo**: La constante `MICROMETERS_PER_TICK = 14.5356` es específica
> del diámetro de rueda y la resolución del encoder magnético. Debe
> recalibrarse si se cambian las ruedas o los encoders.

### Separación entre ruedas

| Parámetro | Valor |
|---|---|
| `WHEELS_SEPARATION` | 0.12 m (120 mm) |

## Giroscopio MPU-6500

### Hardware

| Característica | Detalle |
|---|---|
| **Modelo** | MPU-6500 (TDK/InvenSense) |
| **Interfaz** | SPI3 (PC10=SCK, PC11=MISO, PC12=MOSI, PA15=NSS) |
| **Rango** | ±2000 dps |
| **Sensibilidad** | 16.4 LSB/dps |
| **Filtro DLPF** | 250 Hz bandwidth (DLPF_CFG = 0) |
| **Sample rate interno** | 8 kHz (SMPLRT_DIV = 0) |

### Comunicación SPI

El MPU-6500 requiere dos velocidades SPI diferentes:

| Modo | Velocidad | Uso |
|---|---|-----|
| **Low speed** | ~656 kHz (PCLK1/128) | Escritura de registros |
| **High speed** | ~10.5 MHz (PCLK1/8) | Lectura de datos |

La conmutación se realiza con `setup_spi_low_speed()` y `setup_spi_high_speed()`
en [`setup.c:303-318`](../source_code/src/setup.c#L303-L318).

### Registros relevantes

| Registro | Dirección | Descripción |
|---|---|---|
| `MPU_PWR_MGMT_1` | 107 | Control de sleep/reset |
| `MPU_SIGNAL_PATH_RESET` | 104 | Reset del path de señal |
| `MPU_USER_CTRL` | 106 | Control I2C/SPI |
| `MPU_SMPLRT_DIV` | 25 | Divisor de sample rate |
| `MPU_CONFIG` | 26 | Configuración DLPF |
| `MPU_GYRO_CONFIG` | 27 | Rango del giroscopio |
| `MPU_GYRO_ZOUT_H/L` | 71/72 | Lectura eje Z |
| `MPU_Z_OFFS_USR_H/L` | 23/24 | Offset de calibración Z |
| `MPU_WHOAMI` | 117 | Registro de identidad (0x70) |

### Actualización de lecturas

`update_gyro_readings()` en [`mpu.c:173-179`](../source_code/src/mpu.c#L173-L179):

1. Lee el valor crudo del eje Z vía SPI
2. Aplica un filtro paso bajo: `raw = 0.5 × new + 0.5 × old`
3. Integra el ángulo: `angle −= dps / 1000`

### Conversión de unidades

```
rad/s = raw / 16.4 × (π / 180)
dps   = raw / 16.4
```

### Calibración

El offset se aplica por hardware escribiendo en `MPU_Z_OFFS_USR_H/L`. Esto
simplifica la lectura ya que el valor crudo ya está compensado. Ver
[Calibración](08-calibration.md#calibracion-del-giroscopio-eje-z).

### Fusión sensorial

La corrección angular del lazo de control puede usar el giroscopio, los
sensores de línea, o ambos simultáneamente. La velocidad angular medida por
el giro es la fuente primaria; los sensores de línea corrigen la deriva
lateral. Ver [Control PID](05-control-system.md).

---

*Documento generado el 2026-06-25. Ver también [Sensores](03-sensors.md), [Control PID](05-control-system.md), [Calibración](08-calibration.md).*

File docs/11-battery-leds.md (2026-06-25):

# Batería y LEDs

## Sistema de batería

FujitoraBot2 funciona con baterías LiPo de 2 o 3 celdas (2S/3S) y detecta
automáticamente la configuración conectada.

### Medición de tensión

| Característica | Detalle |
|---|---|
| **ADC** | ADC2, canal 13 (PC3) |
| **Resolución** | 12 bits (0–4095) |
| **LSB** | 3.3 V / 4096 = 0.806 mV |
| **Divisor** | ×3.8673 (`VOLT_DIV_FACTOR`) |
| **Filtro** | Paso bajo α = 0.1 |
| **Frecuencia** | 1 kHz (SysTick) |

### Cálculo

```
V_batería = lectura_ADC × (3.3 / 4096) × 3.8673
V_filtrada = 0.1 × V_actual + 0.9 × V_anterior
```

### Rangos de detección

| Batería | Tensión nominal | Límite bajo | Límite alto |
|---|---|---|---|
| **2S** | 7.4 V | 7.4 V | 8.2 V |
| **3S** | 11.1 V | 11.1 V | 12.6 V |

```mermaid
flowchart TD
    A[Leer V_batería] --> B{V en rango 3S?}
    B -->|11.1–12.6V| C[Modo 3S: V_full = 12.6V]
    B -->|No| D{V en rango 2S?}
    D -->|7.4–8.2V| E[Modo 2S: V_full = 8.2V]
    D -->|No| F[Voltaje fuera de rango]
    C --> G[battery_level = map 0–100%]
    E --> G
```

La detección se realiza en `show_battery_level()`
([`battery.c:27-42`](../source_code/src/battery.c#L27-L42)).

### Visualización de nivel de batería

Al encender, los LEDs de info muestran una barra de nivel de batería durante
750 ms usando `set_leds_battery_level()`.

### Tensión de referencia para control de motores

`get_battery_full_voltage()` devuelve la tensión nominal de la batería detectada
(8.2 V para 2S, 12.6 V para 3S). Este valor se usa en el cálculo de PWM para
compensar la caída de tensión durante la descarga.

## Sistema de LEDs

FujitoraBot2 tiene tres tipos de LEDs:

| Tipo | Cantidad | Control | Descripción |
|---|---|---|---|
| **LED de estado** | 1 | GPIO | Indicador de corazón del sistema |
| **LED RGB** | 1 | TIM1 PWM (4 canales) | Información contextual de menú y calibración |
| **LEDs de info** | 10 | GPIO (PA0–PA7, PC4–PC5) | Indicadores de modo y configuración |

### LED de estado

Controlado por GPIO. Modos disponibles:

| Modo | Función | Descripción |
|---|---|---|
| `set_status_led(true/false)` | On/Off | Estado binario |
| `toggle_status_led()` | Toggle | Alterna el estado |
| `warning_status_led(ms)` | Parpadeo | Parpadeo rápido de advertencia |
| `set_status_heartbeat()` | Latido | Señal de vida continua |

### LED RGB

Controlado por TIM1 con 4 canales PWM a 4 kHz (resolución 1024 pasos):

| Canal TIM1 | Pin | Color |
|---|-----|---|
| CH1 | PA8 | Rojo |
| CH2 | PA9 | Verde |
| CH3 | PA10 | Azul |
| CH4 | PA11 | — (reserva) |

Modos disponibles:

| Modo | Descripción |
|---|---|
| `set_RGB_color(r,g,b)` | Color fijo (0–255 por canal) |
| `warning_RGB_color(r,g,b,ms)` | Parpadeo de color |
| `set_RGB_rainbow()` | Arcoíris continuo (durante calibración) |

### LEDs de info

| Índice | Pin | Significado en menú Run |
|---|-----|---|
| 0–4 | PA0–PA4 | Velocidad seleccionada (barra) |
| 5 | PA5 | Velocidad adaptativa activa |
| 6 | PA6 | BiggerFilter activo |
| 7 | PA7 | Reserva |
| 8 | PC4 | Sensores digitales activos |
| 9 | PC5 | Control por encoders activo |

Modos de grupo:

| Modo | Descripción |
|---|---|
| `set_info_leds()` | Todos encendidos |
| `clear_info_leds()` | Todos apagados |
| `set_info_leds_wave(ms)` | Onda secuencial |
| `set_info_leds_blink(ms)` | Parpadeo sincronizado |

### Apagado en carrera

Al iniciar la carrera, todos los LEDs se apagan (`set_RGB_color(0,0,0)`,
`set_status_led(false)`, `clear_info_leds()`) para evitar interferencias
con los sensores IR de línea.

---

*Documento generado el 2026-06-25. Ver también [Hardware](01-hardware.md), [Menú](06-menu-system.md).*

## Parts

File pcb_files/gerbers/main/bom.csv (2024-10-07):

Designator | Footprint | Quantity | Value | LCSC Part #
BATT_1 | XT30 connector | 1 | Conn_01x02_Female
BT1 | Bluetooth_BLE_1x1cm | 1 | ~
C1, C20 | 0402 | 2 | 4.7uF
C10, C11, C15, C17, C2, C3, C7, CR4, CR5, CR9 | 0402 | 10 | 0.1uF
C12, C8 | 0402 | 2 | 1uF
C13, C18 | 0805 | 2 | 1uF
C14, C19, CR1, CR2, CR3, CR6, CR7, CR8 | 0805 | 8 | 0.1uF
C16 | 0402 | 1 | 0.01uF
C4, C9 | 0402 | 2 | 2.2uF
C5 | 0402 | 1 | 20uF
C6 | 0402 | 1 | 20pF
CR10 | 0805 | 1 | 10uF
D1, D10, D11, D12, D13, D2, D3, D4, D5, D7, D8, D9 | 0805 | 12 | LED
D14 | 1206 | 1 | D
D6 | LED_RGB_5050-6 | 1 | LED_RGB
DC-DC1 | SOP8_with_gnd_pad | 1 | ~
DEIXAME_QUE_PENSE_1 | LQFP-64_10x10mm_P0.5mm | 1 | STM32F405RGT6
ESC1 | Fujitora_ESC | 1 | ESC_x4_15A
IC1, IC2 | SSOP-16_5.3x6.2mm_P0.65mm | 2 | AS5040
J1 | Fujitora_pads_morro | 1 | MORRO1
JP1, JP2, JP3, JP4 | SolderJumper-2_P1.3mm_Open_Pad1.0x1.5mm | 4 | SolderJumper_2_Open
J_ENC_1, J_ENC_2 | FujitoraBot2_PCBmain_Encoder | 2 | Conn_01x04_Socket
J_ENC_1_CONN1, J_ENC_2_CONN1 | FujitoraBot2_PCBmodule_encoder | 2 | Conn_01x04_Pin
J_ESC1 | Fujitora_pads_ESC | 1 | Conn_01x06_Female
L1 | L_Wuerth_HCM-7050 | 1 | L
MODULO_START_STOP1 | IR_Start | 1 | Conn_01x03_Female
MOTOR_1, PIN_AUXILIAR1 | PinHeader_1x03_P2.54mm_Vertical | 2 | Conn_01x03_Female
R1, R10, R11, R12, R13, R15, R2, R3, R4, R5, R9 | 0805 | 11 | 330
R14, R17, R25 | 0402 | 3 | 47k
R16 | 0805 | 1 | 1K
R18, R19, R20, R23, R24 | 0805 | 5 | 47K
R28 | 0402 | 1 | 45K
R29 | 0402 | 1 | 100k
R30 | 0402 | 1 | 60k
R6, R7, R8 | 0402 | 3 | 330
SW1, SW2, SW3 | SW_SPST_B3U-1000P | 3 | SW_Push
SW4 | SW_SPST_B3U-1000P | 1 | SW_Reset
U1 | FujitoraBot2_giro_MPU6500 | 1 | MPU-6500
U2 | SOT-223-3_TabPin2 | 1 | LM1117MP-3.3
USB1 | USB-C ST-Link USART | 1 | HRO-TYPE-C-31-M-12
Y1 | Crystal_SMD_TXC_7M-4Pin_3.2x2.5mm | 1 | Crystal_GND24

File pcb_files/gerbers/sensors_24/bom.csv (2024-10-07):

Designator | Footprint | Quantity | Value | LCSC Part #
C1, C3 | 0805 | 2 | 10uF | C380331
C2, C4 | 0805 | 2 | 0.1uF | C2847428
J1 | Fujitora_pads_morro | 1 | Conn_01x08_Pin
MUX1, MUX2, MUX3 | MUX_CD4051B | 3 | CD4051B | C3007951
R1, R10, R13, R16, R19, R22, R25, R28, R31, R34, R4, R7 | 0402 | 12 | 45 | C3017827
R11, R12, R14, R15, R17, R18, R2, R20, R21, R23, R24, R26, R27, R29, R3, R30, R32, R33, R35, R36, R5, R6, R8, R9 | 0402 | 24 | 10k | C17414
S1, S10, S11, S12, S13, S14, S15, S16, S17, S18, S19, S2, S20, S21, S22, S23, S24, S3, S4, S5, S6, S7, S8, S9 | FujitoraBot2_QRE1113 | 24 | ~ | C81632

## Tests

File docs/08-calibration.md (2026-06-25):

# Calibración

FujitoraBot2 dispone de procedimientos de calibración para el giroscopio y los
sensores de línea. Los valores calibrados se persisten en la EEPROM emulada en
flash.

## Tipos de calibración

| ID | Tipo | Descripción |
|----|---|---|
| `0` | `CALIBRATE_NONE` | Sin calibración activa |
| `1` | `CALIBRATE_GYRO_Z` | Calibración del offset Z del giroscopio |
| `2` | `CALIBRATE_SENSORS` | Calibración de los 24 sensores de línea |
| `3` | `CALIBRATE_STORE_EEPROM` | Guardado manual a EEPROM |

Se accede desde el menú Config → Calibration.

## Calibración del giroscopio (eje Z)

El procedimiento `gyro_z_calibration()` en [`mpu.c:144-161`](../source_code/src/mpu.c#L144-L161):

1. **Requisito**: el robot debe estar completamente inmóvil
2. Se toman 300 muestras del eje Z con un filtro de media móvil (factor 2)
3. Se calcula el offset como el complemento a 2 del promedio
4. El offset se escribe directamente en los registros `MPU_Z_OFFS_USR_H/L`
   del MPU-6500 (compensación por hardware)
5. El valor se guarda en EEPROM para la próxima inicialización

| Parámetro | Valor |
|---|---|
| `MPU_CAL_SAMPLE_NUM` | 300 |
| `MPU_CAL_SAMPLE_US` | 1000 µs |
| `MPU_AVERAGE_FACTOR` | 2 |

## Calibración de sensores de línea

El procedimiento `sensors_calibration()` en
[`sensors.c:80-193`](../source_code/src/sensors.c#L80-L193) soporta dos modos:

### Modo verificación (EEPROM)

Si los valores de calibración ya están en EEPROM:

1. El LED de estado muestra `true` (encendido)
2. Se pasa el robot sobre la línea para verificar que cada sensor detecta
   tanto el mínimo como el máximo dentro de ±200 del valor almacenado
3. LED RGB: rojo = ningún sensor OK, amarillo = algunos OK, verde = todos OK
4. Espera 500 ms adicionales con todos los sensores OK antes de confirmar

### Modo calibración completa

Si se desactiva el uso de EEPROM (botón Down):

1. Se resetean mínimos a 4096 y máximos a 0
2. Durante 5 segundos (`MS_CALIBRACION_LINEA = 5000`) se mueve el robot sobre
   la línea para que cada sensor vea tanto blanco como negro
3. LED RGB muestra arcoíris durante el barrido
4. Se calculan los umbrales como `min + (max − min) × 2/3`
5. Si la diferencia max−min es < 1000 en algún sensor, se muestra error (rojo)
6. Al confirmar, se guardan los 3×24 valores en EEPROM

### Formato de salida

Cada sensor se imprime por UART como:
```
Sensor XX: MIN <> UMB <> MAX
```

(ver [Sensores](03-sensors.md))

## Guardado en EEPROM

La calibración del giroscopio y los sensores se guardan independientemente:

- **Automático**: `gyro_z_calibration()` guarda el offset tras calibrar
- **Automático**: `sensors_calibration()` guarda los 72 valores tras calibrar
- **Manual**: opción `CALIBRATE_STORE_EEPROM` fuerza un guardado completo

(ver [EEPROM](09-storage.md))

---

*Documento generado el 2026-06-25. Ver también [Sensores](03-sensors.md), [Encoders y Giroscopio](10-encoders-gyro.md), [EEPROM](09-storage.md).*

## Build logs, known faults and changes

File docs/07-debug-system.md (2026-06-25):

# Debug

FujitoraBot2 dispone de un sistema de debug por UART/USART3 con múltiples modos
de visualización y un buffer de telemetría (MacroArray) para análisis
post-carrera.

## Comunicación UART

| Característica | Detalle |
|---|---|
| **Periférico** | USART3 |
| **Pines** | PB10 (TX), PB11 (RX) |
| **Baudrate** | 115200 |
| **Formato** | 8N1 |
| **Redirección** | `printf` → `_write()` → USART3 |

La redirección de `printf` se implementa en [`usart.c`](../source_code/src/usart.c)
sobrescribiendo `_write()`.

## Modos de debug

Los modos se seleccionan desde el menú Config → Debug. Cada modo muestra datos
en tiempo real por UART:

| ID | Modo | Descripción |
|----|---|---|
| `0` | `DEBUG_NONE` | Sin salida |
| `1` | `DEBUG_MACROARRAY` | Vuelca el buffer de telemetría |
| `2` | `DEBUG_TYPE_SENSORS_RAW` | Lecturas crudas de los 24 sensores |
| `3` | `DEBUG_TYPE_SENSORS_CALIBRATED` | Lecturas calibradas de los 24 sensores |
| `4` | `DEBUG_TYPE_LINE_POSITION` | Posición de línea calculada |
| `5` | `DEBUG_TYPE_MOTORS` | PWM y velocidades de motores |
| `6` | `DEBUG_TYPE_ENCODERS` | Lecturas de encoders y odometría |
| `7` | `DEBUG_TYPE_DIGITAL_IO` | Estado de entradas/salidas digitales |
| `8` | `DEBUG_TYPE_CORRECCION_POSICION` | Corrección de posición (error, voltajes) |
| `9` | `DEBUG_TYPE_LEDS_PARTY` | Demo de LEDs |
| `10` | `DEBUG_TYPE_FANS_DEMO` | Demo de ventilador |

## MacroArray

Buffer circular de telemetría que almacena variables durante la carrera para
su análisis posterior:

| Capacidad | 30 000 registros |
|---|---|
| **Duración máxima** | ~30 s a 1 kHz |
| **Formato** | Entradas de tamaño variable con timestamp |
| **Salida** | Plot (separado por `\n`) o Tabs (separado por `\t`) |

### Datos registrados en carrera

Cada iteración del lazo de control almacena 9 valores:

```
[timestamp, target_speed, ideal_speed, measured_speed,
 line_position, linear_voltage, angular_voltage,
 pwm_left, pwm_right, battery_voltage]
```

El buffer se vuelca por UART con el modo `DEBUG_MACROARRAY` tras la carrera
para análisis con herramientas externas (Serial Plotter, hojas de cálculo).

### Canales alternativos

Existen canales adicionales comentados en el código para activar según
necesidad de diagnóstico:

- **Canal 1**: error de sensores de línea + voltaje angular
- **Canal 4**: velocidad lineal, angular + posición cartesiana (X, Y)

## LEDs de estado

| LED | Color | Significado |
|-----|---|---|
| **Status** | Azul | Estado general (heartbeat, warning) |
| **RGB** | RGB | Información contextual del menú y carrera |
| **Info 0–9** | Azul | Indicadores de modo y configuración |

El LED RGB se apaga completamente (`set_RGB_color(0,0,0)`) al iniciar la
carrera para no interferir con los sensores IR.

---

*Documento generado el 2026-06-25. Ver también [Menú](06-menu-system.md), [Control PID](05-control-system.md).*

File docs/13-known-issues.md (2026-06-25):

# Problemas Conocidos

> **Última revisión**: 2026-06-25 (commit `8a8beb2` — doc-init inicial)
> **Total**: 29 issues — 6 críticos, 9 moderados, 14 leves

---

## 🔴 Críticos — Riesgo de fallo catastrófico

### BL-01 — Límites de batería 2S invertidos: detección nunca se activa

- **Archivo**: [`config.h:40-41`](../source_code/include/config.h#L40-L41), [`battery.c:34`](../source_code/src/battery.c#L34)
- **Descripción**: `BATTERY_2S_HIGH_LIMIT_VOLTAGE = 7.4` y `BATTERY_2S_LOW_LIMIT_VOLTAGE = 8.2` están invertidos (HIGH < LOW). La condición `voltage >= 8.2 && voltage <= 7.4` es **siempre falsa**. Las baterías 2S nunca se detectan; `battery_full_voltage` se queda en el valor por defecto (11.1V de 3S) y el nivel de batería siempre es 0%.
- **Impacto**: Alto — con batería 2S, la compensación de tensión en el cálculo de PWM usa un voltaje de referencia incorrecto (11.1V en vez de ~8.4V), causando que los motores reciban menos potencia de la esperada. El indicador de nivel de batería no funciona.
- **Solución propuesta**: Intercambiar los valores:
  ```c
  #define BATTERY_2S_LOW_LIMIT_VOLTAGE 7.4
  #define BATTERY_2S_HIGH_LIMIT_VOLTAGE 8.4
  ```

### CT-01 — PID de velocidad lineal es control I puro sin término proporcional ni derivativo

- **Archivo**: [`control.c:251-257`](../source_code/src/control.c#L251-L257), [`config.h:20-21`](../source_code/include/config.h#L20-L21)
- **Descripción**: La variable `linear_error` acumula la integral del error de velocidad (`linear_error += ...`). `KP_LINEAR = 0.00025` multiplica esta integral (actúa como ganancia integral, no proporcional). `KD_LINEAR = 0.00//3` está anulado por el comentario `//3`. El control resultante es **integral puro** sin respuesta proporcional ni amortiguamiento derivativo, lo que causa overshoot y oscilación en la respuesta de velocidad.
- **Impacto**: Alto — sin término proporcional, el robot no responde inmediatamente a cambios de velocidad; sin derivativo, no hay amortiguamiento. Esto degrada el seguimiento de velocidad en aceleraciones y frenadas.
- **Solución propuesta**: Reestructurar como PID estándar:
  ```c
  float error = ideal_linear_speed - get_measured_linear_speed();
  integral_linear_error += error;
  // anti-windup simétrico
  linear_voltage = KP * error + KI * integral_linear_error + KD * (error - last_error);
  ```
  Y definir constantes separadas `KP`, `KI`, `KD` con valores apropiados.

### SW-01 — Variables compartidas ISR↔main sin cualificador `volatile`

- **Archivo**: [`control.c:3`](../source_code/src/control.c#L3), [`menu_run.c:18`](../source_code/src/menu_run.c#L18), [`motors.c:3`](../source_code/src/motors.c#L3), [`buttons.c:3-6`](../source_code/src/buttons.c#L3-L6), [`kinematics.c:59`](../source_code/src/kinematics.c#L59)
- **Descripción**: Las siguientes variables se leen y escriben desde contexto de ISR y desde el main loop sin cualificador `volatile`:
  - `race_started` (control.c) — ISR TIM5 / main loop
  - `valueRun[]` (menu_run.c) — ISR TIM5 / main loop
  - `escInited` (motors.c) — ISR SysTick / ISR TIM5
  - `ir_start_ms`, `btn_menu_up_ms`, `btn_menu_down_ms`, `btn_menu_mode_ms` (buttons.c) — ISR SysTick / main loop
  - `kinematics` (kinematics.c) — main loop / ISR TIM5
- **Impacto**: Alto — el compilador puede cachear estas variables en registros, causando que la ISR lea valores stale o que el main loop nunca vea cambios hechos por la ISR. Podría impedir el arranque de carrera o causar lecturas incorrectas de botones.
- **Mitigación actual**: Ninguna. En la práctica funciona porque las variables se leen en cada iteración y el compilador con `-Os` tiende a re-leer de memoria, pero no está garantizado.
- **Solución propuesta**: Añadir `volatile` a todas las declaraciones listadas.

### CT-02 — División por cero en `voltage_to_motor_pwm()` al inicio

- **Archivo**: [`control.c:49`](../source_code/src/control.c#L49), [`battery.c:4`](../source_code/src/battery.c#L4)
- **Descripción**: `battery_voltage` se inicializa a `0.0f`. `voltage_to_motor_pwm()` divide por `get_battery_voltage()` sin comprobar que sea > 0. Si el lazo de control se ejecuta antes de que el filtro paso-bajo de batería produzca un valor válido, la división por cero en FPU genera NaN/inf que se propaga al PWM de los motores.
- **Impacto**: Alto — PWM indefinido en los primeros milisegundos tras el arranque. Podría causar un movimiento brusco e inesperado de los motores.
- **Solución propuesta**: Añadir guarda:
  ```c
  float batt = get_battery_voltage();
  if (batt <= 0.001f) return 0;
  return voltage / batt * (MOTORS_MAX_PWM / 2);
  ```

### EE-01 — Borrado/programación de flash con interrupciones habilitadas

- **Archivo**: [`eeprom.c:22-27`](../source_code/src/eeprom.c#L22-L27)
- **Descripción**: `eeprom_save()` llama a `flash_erase_sector(11)` y `flash_program_word()` con las interrupciones habilitadas. El sector 11 está en el banco 1 de flash (0x080E0000). Si cualquier ISR (SysTick @ 1kHz, TIM5 @ 1kHz, DMA) se dispara durante el borrado, la CPU intenta leer el vector de interrupción del banco 1 bloqueado → hard fault.
- **Impacto**: Alto — crashea el sistema al guardar configuración (ej. al activar Race Mode desde el menú, que llama a `eeprom_save()`).
- **Mitigación actual**: El guardado solo ocurre cuando el usuario interactúa con el menú, no durante la carrera. Pero el riesgo es real cada vez que se guarda.
- **Solución propuesta**: Deshabilitar interrupciones durante la operación:
  ```c
  __disable_irq();
  flash_unlock();
  flash_erase_sector(EEPROM_SECTOR, FLASH_CR_PROGRAM_X16);
  // ... program words ...
  flash_lock();
  __enable_irq();
  ```

### CT-03 — Términos de corrección stale aplicados cuando la corrección está desactivada

- **Archivo**: [`control.c:269-279`](../source_code/src/control.c#L269-L279)
- **Descripción**: Cuando `line_sensors_correction_enabled = false`, los términos `line_sensors_error`, `sum_line_sensors_error` y `last_line_sensors_error` no se actualizan (bloque `if` en línea 269), pero sus **valores anteriores** siguen contribuyendo a `angular_voltage` en la línea 279. Si la corrección por sensores se desactiva en mitad de una curva, el error stale fuerza una corrección angular incorrecta.
- **Impacto**: Alto — corrección angular fantasma tras desactivar sensores de línea. Puede desestabilizar el robot en recta si la última lectura fue en curva.
- **Solución propuesta**: Gatear la contribución a `angular_voltage`:
  ```c
  float angular_voltage = 0;
  if (mpu_correction_enabled) { angular_voltage += ...; }
  if (line_sensors_correction_enabled) { angular_voltage += ...; }
  ```

---

## 🟡 Moderados — Riesgo de comportamiento incorrecto

### CT-04 — `set_target_fan_speed()` divide por `ms` sin comprobar cero

- **Archivo**: [`control.c:228`](../source_code/src/control.c#L228)
- **Descripción**: `fan_speed_accel = (fan_speed - ideal_fan_speed) * CONTROL_FREQUENCY_HZ / ms`. Si `ms = 0`, división por cero. Todos los callers actuales pasan 500, pero no hay defensa.
- **Impacto**: Medio — solo si se añade un caller con `ms = 0`.
- **Solución propuesta**: Añadir `if (ms <= 0) return;` al inicio de la función.

### CT-05 — Anti-windup de `linear_error` solo en dirección positiva

- **Archivo**: [`control.c:254-256`](../source_code/src/control.c#L254-L256)
- **Descripción**: El clamp `if (linear_error > 8000) linear_error = 8000` solo actúa en dirección positiva. Si el robot frena bruscamente o la velocidad medida supera la ideal, la integral negativa crece sin límite, causando una recuperación lenta al volver a acelerar.
- **Impacto**: Medio — afecta la respuesta de frenada y re-aceleración.
- **Solución propuesta**: Añadir clamp simétrico: `else if (linear_error < -8000) linear_error = -8000`.

### CT-06 — `angular_error` y `sum_line_sensors_error` sin anti-windup

- **Archivo**: [`control.c:266`](../source_code/src/control.c#L266), [`control.c:272`](../source_code/src/control.c#L272)
- **Descripción**: Ambas integrales crecen sin límite. `angular_error` acumula `ideal_angular_speed - measured` (ideal=0 siempre, así que acumula `-gyro_bias`). Con `KP_ANGULAR = 0.04`, un bias de 1º/s produce ~0.06 rad/s de corrección espuria tras 10 segundos. `sum_line_sensors_error` tiene `KI_LINE_SENSORS = 0` actualmente, así que es latente.
- **Impacto**: Medio — `angular_error` causa deriva en la corrección angular durante carreras largas. `sum_line_sensors_error` es latente hasta que se active `KI_LINE_SENSORS`.
- **Solución propuesta**: Añadir clamping condicional a ambas integrales.

### EG-01 — Calibración del giroscopio usa media móvil en vez de promedio real

- **Archivo**: [`mpu.c:152`](../source_code/src/mpu.c#L152)
- **Descripción**: `zout_av = (raw + zout_av) / 2` aplica un filtro de media móvil exponencial con α = 0.5. Tras 300 muestras, el resultado está dominado por las últimas ~2 lecturas, no por el promedio de las 300. La calibración es sensible al ruido de las últimas muestras.
- **Impacto**: Medio — el offset del giro puede tener un error de varios LSB, causando deriva angular.
- **Solución propuesta**: Usar promedio acumulativo real: acumular en `int32_t`, dividir entre 300 al final.

### SS-01 — ADC2 corrompe el orden de canales de ADC1

- **Archivo**: [`sensors.c:217-218`](../source_code/src/sensors.c#L217-L218), [`battery.c:7`](../source_code/src/battery.c#L7)
- **Descripción**: El desarrollador dejó comentarios de advertencia indicando que activar ADC2 (batería) desordena los canales de ADC1. Las lecturas de los sensores de línea pueden asignarse a posiciones incorrectas del array `sensors_raw[]`.
- **Impacto**: Medio — si los canales se intercambian, la posición de línea calculada es errónea, causando zigzag o salida de pista.
- **Mitigación actual**: El mapeo actual en `sensors_update_mux_readings()` (línea 219-221) parece ser el resultado de ajustes empíricos para compensar el desorden.
- **Solución propuesta**: Investigar la configuración de `ADC_CCR` (registro común de ADC) en STM32F4. Posiblemente falte configuración del modo dual-ADC o la sincronización de relojes entre ADC1 y ADC2.

### HW-01 — `CONTROL_FREQUENCY_HZ` no coincide con la frecuencia real de TIM5

- **Archivo**: [`constants.h:14`](../source_code/include/constants.h#L14), [`setup.c:241`](../source_code/src/setup.c#L241)
- **Descripción**: `CONTROL_FREQUENCY_HZ = 1000`, pero TIM5 está configurado con prescaler 82 y período 1024 sobre un reloj de 84 MHz: frecuencia real = 84 MHz / 83 / 1024 ≈ 988 Hz. Las rampas de aceleración (`linear_accel / CONTROL_FREQUENCY_HZ`) son ~1.2% más lentas de lo esperado.
- **Impacto**: Medio — error acumulativo en distancias de aceleración/frenada.
- **Solución propuesta**: Ajustar `timer_set_period(TIM5, 1012)` y `timer_set_prescaler(TIM5, 82)` para obtener exactamente 1000 Hz, o definir `CONTROL_FREQUENCY_HZ 988`.

### MN-01 — `millisPasados` truncado a 16 bits con riesgo de overflow

- **Archivo**: [`main.c:48-50`](../source_code/src/main.c#L48-L50)
- **Descripción**: `uint16_t millisPasados = get_clock_ticks() - millisInicio` trunca un `uint32_t` a 16 bits. Si `get_start_millis() > 65535` (65.5 s), el contador wrapa y el fade del LED RGB durante la cuenta atrás es incorrecto.
- **Impacto**: Medio — solo afecta al indicador visual de cuenta atrás, no a la carrera. Pero con cuentas atrás largas (>65s) el LED muestra valores incorrectos.
- **Solución propuesta**: Cambiar `uint16_t millisPasados` a `uint32_t millisPasados`.

### SW-02 — `delay()` sin protección contra wrap-around del timer

- **Archivo**: [`delay.c:26-30`](../source_code/src/delay.c#L26-L30)
- **Descripción**: `delay()` calcula `awake = clock_ticks + ms` y espera `awake > clock_ticks`. Cuando `clock_ticks` está cerca de `UINT32_MAX` (~49.7 días de uptime), la suma wrapa y la función retorna inmediatamente. El mismo patrón incorrecto aparece en `main.c:49`, `sensors.c:151` y `sensors.c:312`.
- **Impacto**: Medio — no es relevante para carreras (< 1 minuto), pero sí para sesiones de desarrollo largas o si el robot se deja encendido días.
- **Solución propuesta**: Usar el patrón seguro:
  ```c
  uint32_t start = clock_ticks;
  while ((clock_ticks - start) < ms);
  ```

### BL-02 — Rango de tensión 8.2V–11.1V sin manejar

- **Archivo**: [`battery.c:31-36`](../source_code/src/battery.c#L31-L36)
- **Descripción**: Una batería 3S descargada a < 11.1V o una 2S completamente cargada a > 8.2V cae en un hueco donde ninguna de las dos ramas de detección aplica. `battery_level` se queda en 0 y `battery_full_voltage` conserva el valor por defecto.
- **Impacto**: Medio — nivel de batería incorrecto en el margen entre 2S cargada y 3S descargada.
- **Solución propuesta**: Fusionar en un solo rango continuo o añadir una tercera rama para voltajes en el hueco, asignando al tipo de batería más probable según el valor.

---

## 🟢 Leves — Riesgo de mantenibilidad o comportamiento menor

### SW-03 — `#elif CONFIG_RUN_DEBUG` sin `defined()`

- **Archivo**: [`config.c:11,26`](../source_code/src/config.c#L11), [`sensors.c:65-66`](../source_code/src/sensors.c#L65-L66)
- **Descripción**: `#elif CONFIG_RUN_DEBUG` evalúa un macro no definido como 0 (false), que es el comportamiento deseado. Pero si alguien define `CONFIG_RUN_DEBUG 0`, `#elif 0` también es false — la intención no se cumple. Lo mismo para `#elif CONFIG_LINE_WHITE`.
- **Impacto**: Bajo — funciona por accidente, pero es frágil.
- **Solución propuesta**: Usar `#elif defined(CONFIG_RUN_DEBUG)` y `#elif defined(CONFIG_LINE_WHITE)`.

### SW-04 — Variables globales sin `static`

- **Archivo**: [`calibrations.c:3`](../source_code/src/calibrations.c#L3), [`debug.c:3-4`](../source_code/src/debug.c#L3-L4), [`buttons.c:3-6`](../source_code/src/buttons.c#L3-L6), [`menu_run.c:9,18,20`](../source_code/src/menu_run.c#L9)
- **Descripción**: `calibration_enabled`, `debug_enabled`, `last_print_debug`, `ir_start_ms`, `btn_menu_up_ms`, `btn_menu_down_ms`, `btn_menu_mode_ms`, `modeRun`, `valueRun[]`, `lastBlinkMs`, `blinkState` son globales sin `static`. Pueden causar colisiones de nombres con otros módulos.
- **Impacto**: Bajo — no hay colisiones reales hoy, pero es frágil ante nuevos módulos.
- **Solución propuesta**: Añadir `static` a todas estas declaraciones.

### KN-01 — `configure_kinematics()` sin bounds check

- **Archivo**: [`kinematics.c:62`](../source_code/src/kinematics.c#L62)
- **Descripción**: `kinematics = kinematics_settings[speed]` indexa el array con un `enum speed_strategy` sin verificar que `speed <= SPEED_HAKI`. Un valor corrupto (ej. por memory corruption o un bug en el menú) leería basura de la memoria adyacente.
- **Impacto**: Bajo — requiere corrupción de memoria o bug en menú para manifestarse.
- **Solución propuesta**: Añadir `if (speed < 0 || speed > SPEED_HAKI) speed = SPEED_TEST;`.

### EG-02 — Typo en nombre de función: `get_encoder_curernt_angle`

- **Archivo**: [`encoders.h:28`](../source_code/include/encoders.h#L28), [`encoders.c:93`](../source_code/src/encoders.c#L93)
- **Descripción**: `curernt` en vez de `current`. La función compila y funciona, pero el nombre es confuso.
- **Impacto**: Bajo — solo afecta a la legibilidad.
- **Solución propuesta**: Renombrar a `get_encoder_current_angle` en header y fuente.

### EE-02 — `eeprom_set_data()` sin bounds check

- **Archivo**: [`eeprom.c:56-63`](../source_code/src/eeprom.c#L56-L63)
- **Descripción**: Si `index + length > DATA_LENGTH`, se escribe fuera del array `eeprom_data[]`. Todos los callers actuales respetan los límites, pero no hay defensa.
- **Impacto**: Bajo — requiere un bug en un caller para manifestarse.
- **Solución propuesta**: Añadir `if (index + length > DATA_LENGTH || !data) return;`.

### BL-03 — Rainbow LED: comparación `<= 0` sobre `uint32_t`

- **Archivo**: [`leds.c:108-111`](../source_code/src/leds.c#L108-L111)
- **Descripción**: `rainbowRGB[rainbowColorDesc] <= 0` sobre `uint32_t` es equivalente a `== 0`. Al decrementar de 20 en 20, el valor salta de 4 a 0xFFFFFFF0 (wrap), nunca pasa por 0, así que la condición nunca se cumple. El canal experimenta un flash blanco breve antes de que el otro límite (`>= LEDS_MAX_PWM/4`) fuerce la transición.
- **Impacto**: Bajo — flicker apenas perceptible en el LED RGB durante la calibración.
- **Solución propuesta**: Usar `<= 20` o clamp explícito antes del decremento.

### SS-02 — `delay_us(0)` como NOP frágil para timing de SPI del MPU

- **Archivo**: [`mpu.c:60`](../source_code/src/mpu.c#L60)
- **Descripción**: El comentario del desarrollador indica que `delay_us(0)` es necesario para que el MPU "no se prenda fuego". Pero `delay_us(0)` no garantiza ningún ciclo de espera — solo el overhead de la llamada a función. Un cambio de compilador u optimización podría eliminarlo.
- **Impacto**: Bajo — el MPU funciona actualmente, pero es frágil.
- **Solución propuesta**: Reemplazar con `delay_us(1)` o `__asm__("nop"); __asm__("nop"); __asm__("nop");`.

### SS-03 — VLAs en stack durante calibración de sensores

- **Archivo**: [`sensors.c:99-100`](../source_code/src/sensors.c#L99-L100)
- **Descripción**: `bool sensorsMinChecked[get_sensors_num()]` y `bool sensorsMaxChecked[get_sensors_num()]` son arrays de longitud variable (VLA) en el stack. Con 24 sensores son 48 bytes — seguro hoy, pero frágil si `NUM_SENSORS` aumenta.
- **Impacto**: Bajo — seguro con la configuración actual.
- **Solución propuesta**: Usar arrays de tamaño fijo `bool sensorsMinChecked[NUM_SENSORS]`.

### SS-04 — `round()` usa aritmética `double` en Cortex-M4F

- **Archivo**: [`sensors.c:270`](../source_code/src/sensors.c#L270)
- **Descripción**: `round(map(...))` llama a `round(double)` que requiere emulación software en Cortex-M4F (single-precision FPU). Es más lento y aumenta el tamaño del binario.
- **Impacto**: Bajo — llamado una vez por ms en el SysTick, el overhead es mínimo.
- **Solución propuesta**: Usar `roundf()` (single-precision).

### DB-01 — `debug_motors()` aplica PWM sin confirmación

- **Archivo**: [`debug.c`](../source_code/src/debug.c) — función `debug_motors()`
- **Descripción**: El modo debug de motores aplica `set_motors_speed(15, 15)` sin ninguna confirmación ni guarda. Si se activa por error con el robot sobre la mesa, los motores giran inesperadamente.
- **Impacto**: Bajo — solo en modo debug, requiere interacción deliberada con el menú.
- **Solución propuesta**: Añadir una secuencia de confirmación (ej. pulsar dos botones simultáneamente) antes de activar los motores en modo debug.

### SW-05 — Include guard `MOVE_H` no coincide con `kinematics.h`

- **Archivo**: [`kinematics.h:1`](../source_code/include/kinematics.h#L1)
- **Descripción**: El header usa `#ifndef MOVE_H` pero el archivo se llama `kinematics.h`. Si algún día existe un `move.h` con guard `MOVE_H`, habrá colisión silenciosa.
- **Impacto**: Bajo — no hay `move.h` actualmente.
- **Solución propuesta**: Cambiar a `#ifndef KINEMATICS_H`.

### SW-06 — Prescaler de timers con fórmula no comprendida por el autor

- **Archivo**: [`setup.c:189,218,238`](../source_code/src/setup.c#L189)
- **Descripción**: `timer_set_prescaler(TIM1, rcc_apb2_frequency * 2 / 4000000 - 2)` tiene un comentario que admite no entender por qué funciona. La fórmula `* 2 / 4000000 - 2` es frágil ante cambios de reloj.
- **Impacto**: Bajo — funciona hoy, pero es una trampa de mantenimiento.
- **Solución propuesta**: Documentar la derivación: `(APB2_freq * 2 / target_freq) - 1`, donde `*2` es porque el timer recibe 2× APB2 cuando APB prescaler > 1.

### SW-07 — `PI` con solo 5 cifras significativas

- **Archivo**: [`constants.h:5`](../source_code/include/constants.h#L5)
- **Descripción**: `#define PI 3.1415` tiene ~0.003% de error. Afecta conversiones giroscópicas (rad/s, integración angular).
- **Impacto**: Bajo — error acumulativo despreciable en carreras de < 1 minuto.
- **Solución propuesta**: `#define PI 3.14159265f`.

### DB-02 — LED de info 7 sin uso

- **Archivo**: [`menu_run.c`](../source_code/src/menu_run.c), [`leds.c:221`](../source_code/src/leds.c#L221)
- **Descripción**: El LED índice 7 (PA6) nunca se referencia en `menu_run_handler()`. Es hardware instalado pero sin función asignada, o se perdió un modo de menú que debería usarlo.
- **Impacto**: Bajo — no afecta funcionalidad.
- **Solución propuesta**: Asignar LED 7 a un nuevo indicador o documentar que es reserva.

---

## Correcciones recientes

*(Ninguna — documento creado en la auditoría inicial del 2026-06-25.)*

---

*Documento generado el 2026-06-25. Actualizar con `/doc-review` tras cambios de código.*

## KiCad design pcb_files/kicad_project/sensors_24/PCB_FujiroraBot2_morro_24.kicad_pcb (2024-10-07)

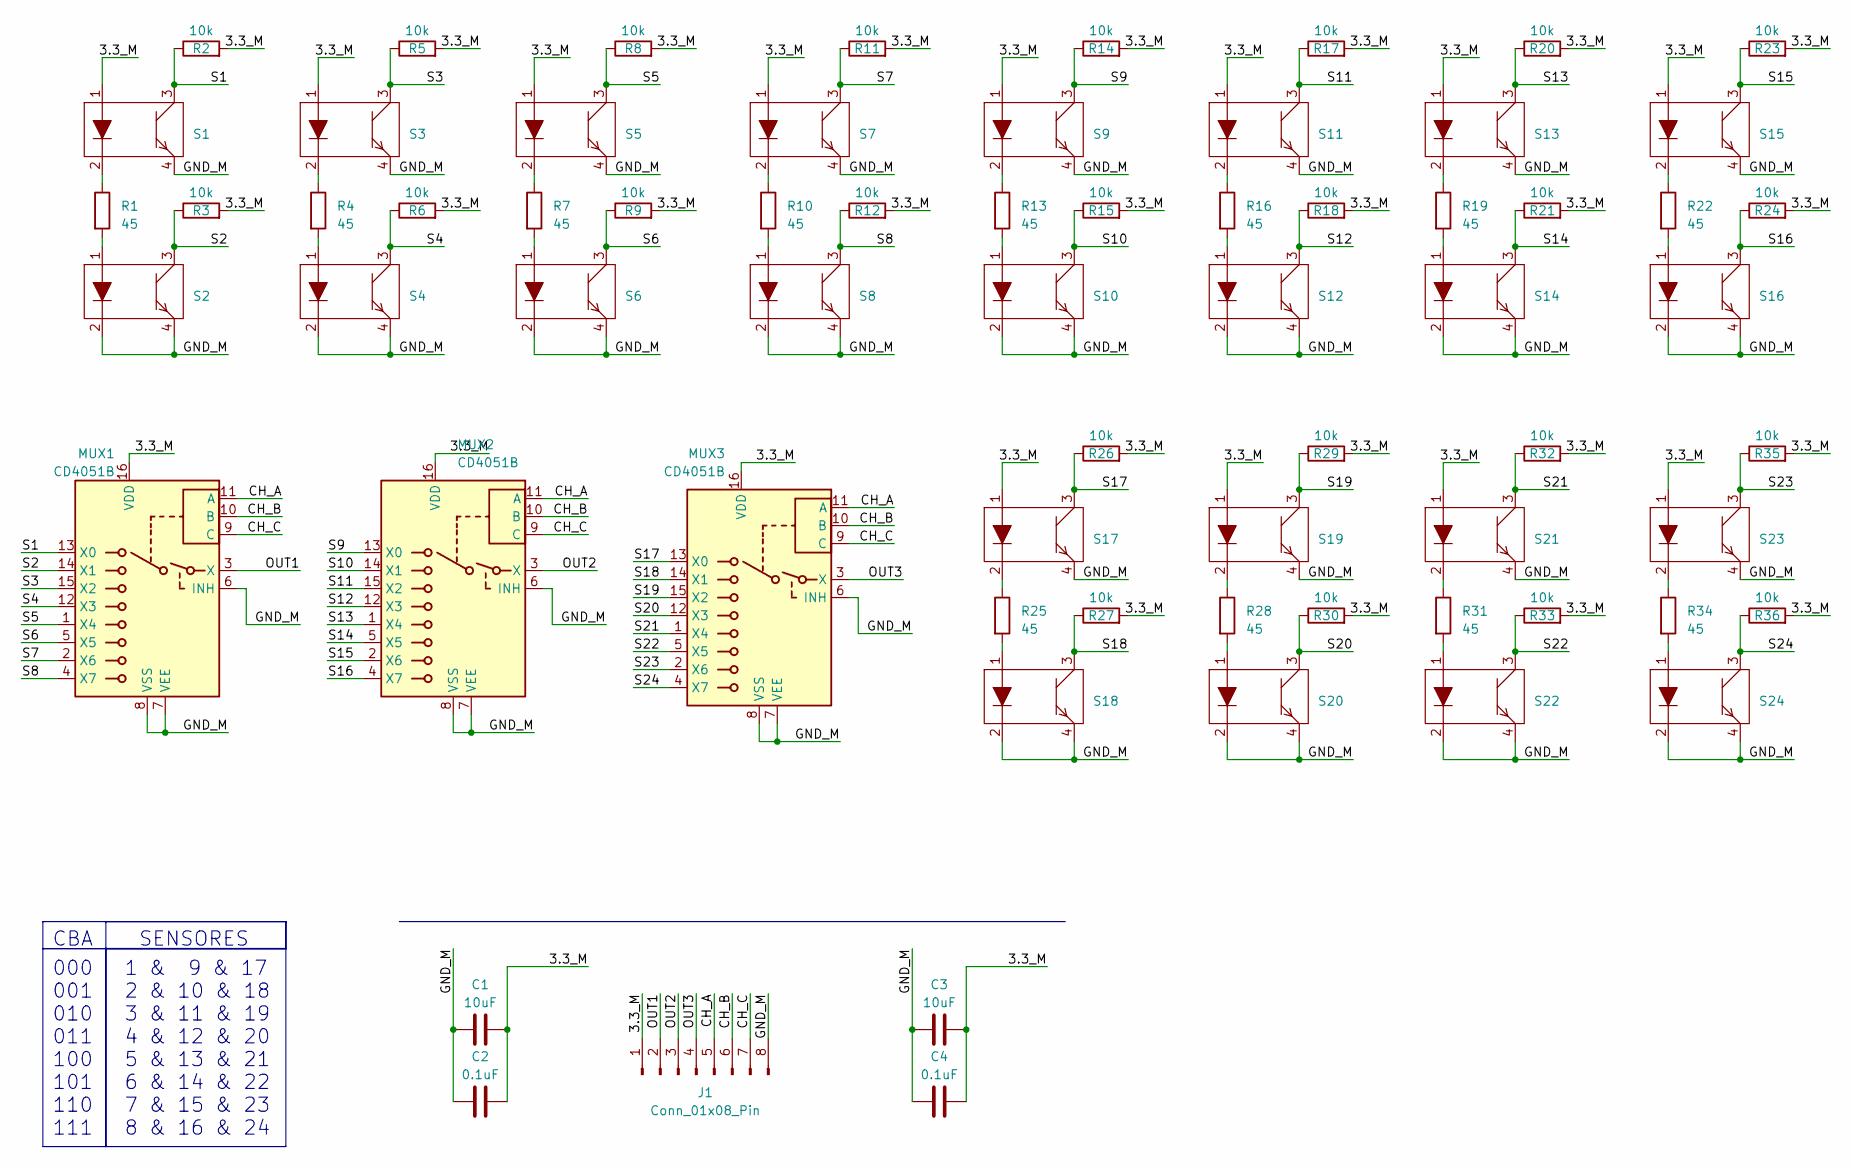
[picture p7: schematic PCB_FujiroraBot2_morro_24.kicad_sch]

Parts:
C1, C3: 10uF; C_0805_2012Metric_Pad1.18x1.45mm_HandSolder; LCSC Part # C380331
C2, C4: 0.1uF; C_0805_2012Metric_Pad1.18x1.45mm_HandSolder; LCSC Part # C2847428
J1: Conn_01x08_Pin; Fujitora_pads_morro
MUX1, MUX2, MUX3: CD4051B; MUX_CD4051B; LCSC Part # C3007951
R1, R4, R7, R10, R13, R16, R19, R22, R25, R28, R31, R34: 45; R_0402_1005Metric_Pad0.72x0.64mm_HandSolder; LCSC Part # C3017827
R2, R3, R5, R6, R8, R9, R11, R12, R14, R15, R17, R18, R20, R21, R23, R24, R26, R27, R29, R30, R32, R33, R35, R36: 10k; R_0402_1005Metric_Pad0.72x0.64mm_HandSolder; LCSC Part # C17414
S1, S2, S3, S4, S5, S6, S7, S8, S9, S10, S11, S12, S13, S14, S15, S16, S17, S18, S19, S20, S21, S22, S23, S24: FujitoraBot2_QRE1113; LCSC Part # C81632

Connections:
/3.3_M: C1.1, C2.1, C3.1, C4.1, J1.1, MUX1.16 (VDD), MUX2.16 (VDD), MUX3.16 (VDD), R2.2, R3.2, R5.2, R6.2, R8.2, R9.2, R11.2, R12.2, R14.2, R15.2, R17.2, R18.2, R20.2, R21.2, R23.2, R24.2, R26.2, R27.2, R29.2, R30.2, R32.2, R33.2, R35.2, R36.2, S1.1, S3.1, S5.1, S7.1, S9.1, S11.1, S13.1, S15.1, S17.1, S19.1, S21.1, S23.1
/CH_A: J1.5, MUX1.11 (A), MUX2.11 (A), MUX3.11 (A)
/CH_B: J1.6, MUX1.10 (B), MUX2.10 (B), MUX3.10 (B)
/CH_C: J1.7, MUX1.9 (C), MUX2.9 (C), MUX3.9 (C)
/GND_M: C1.2, C2.2, C3.2, C4.2, J1.8, MUX1.6 (INH), MUX1.7 (VEE), MUX1.8 (VSS), MUX2.6 (INH), MUX2.7 (VEE), MUX2.8 (VSS), MUX3.6 (INH), MUX3.7 (VEE), MUX3.8 (VSS), S1.4, S2.2, S2.4, S3.4, S4.2, S4.4, S5.4, S6.2, S6.4, S7.4, S8.2, S8.4, S9.4, S10.2, S10.4, S11.4, S12.2, S12.4, S13.4, S14.2, S14.4, S15.4, S16.2, S16.4, S17.4, S18.2, S18.4, S19.4, S20.2, S20.4, S21.4, S22.2, S22.4, S23.4, S24.2, S24.4
/OUT1: J1.2, MUX1.3 (X)
/OUT2: J1.3, MUX2.3 (X)
/OUT3: J1.4, MUX3.3 (X)
/S1: MUX1.13 (X0), R2.1, S1.3
/S2: MUX1.14 (X1), R3.1, S2.3
/S3: MUX1.15 (X2), R5.1, S3.3
/S4: MUX1.12 (X3), R6.1, S4.3
/S5: MUX1.1 (X4), R8.1, S5.3
/S6: MUX1.5 (X5), R9.1, S6.3
/S7: MUX1.2 (X6), R11.1, S7.3
/S8: MUX1.4 (X7), R12.1, S8.3
/S9: MUX2.13 (X0), R14.1, S9.3
/S10: MUX2.14 (X1), R15.1, S10.3
/S11: MUX2.15 (X2), R17.1, S11.3
/S12: MUX2.12 (X3), R18.1, S12.3
/S13: MUX2.1 (X4), R20.1, S13.3
/S14: MUX2.5 (X5), R21.1, S14.3
/S15: MUX2.2 (X6), R23.1, S15.3
/S16: MUX2.4 (X7), R24.1, S16.3
/S17: MUX3.13 (X0), R26.1, S17.3
/S18: MUX3.14 (X1), R27.1, S18.3
/S19: MUX3.15 (X2), R29.1, S19.3
/S20: MUX3.12 (X3), R30.1, S20.3
/S21: MUX3.1 (X4), R32.1, S21.3
/S22: MUX3.5 (X5), R33.1, S22.3
/S23: MUX3.2 (X6), R35.1, S23.3
/S24: MUX3.4 (X7), R36.1, S24.3
unnamed: R1.1, S1.2
unnamed: R1.2, S2.1
unnamed: R4.1, S3.2
unnamed: R4.2, S4.1
unnamed: R7.1, S5.2
unnamed: R7.2, S6.1
unnamed: R10.1, S7.2
unnamed: R10.2, S8.1
unnamed: R13.1, S9.2
unnamed: R13.2, S10.1
unnamed: R16.1, S11.2
unnamed: R16.2, S12.1
unnamed: R19.1, S13.2
unnamed: R19.2, S14.1
unnamed: R22.1, S15.2
unnamed: R22.2, S16.1
unnamed: R25.1, S17.2
unnamed: R25.2, S18.1
unnamed: R28.1, S19.2
unnamed: R28.2, S20.1
unnamed: R31.1, S21.2
unnamed: R31.2, S22.1
unnamed: R34.1, S23.2
unnamed: R34.2, S24.1

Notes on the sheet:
SENSORES
000 001 010 011 100 101 110 111
1 & 9 & 17 2 & 10 & 18 3 & 11 & 19 4 & 12 & 20 5 & 13 & 21 6 & 14 & 22 7 & 15 & 23 8 & 16 & 24
CBA

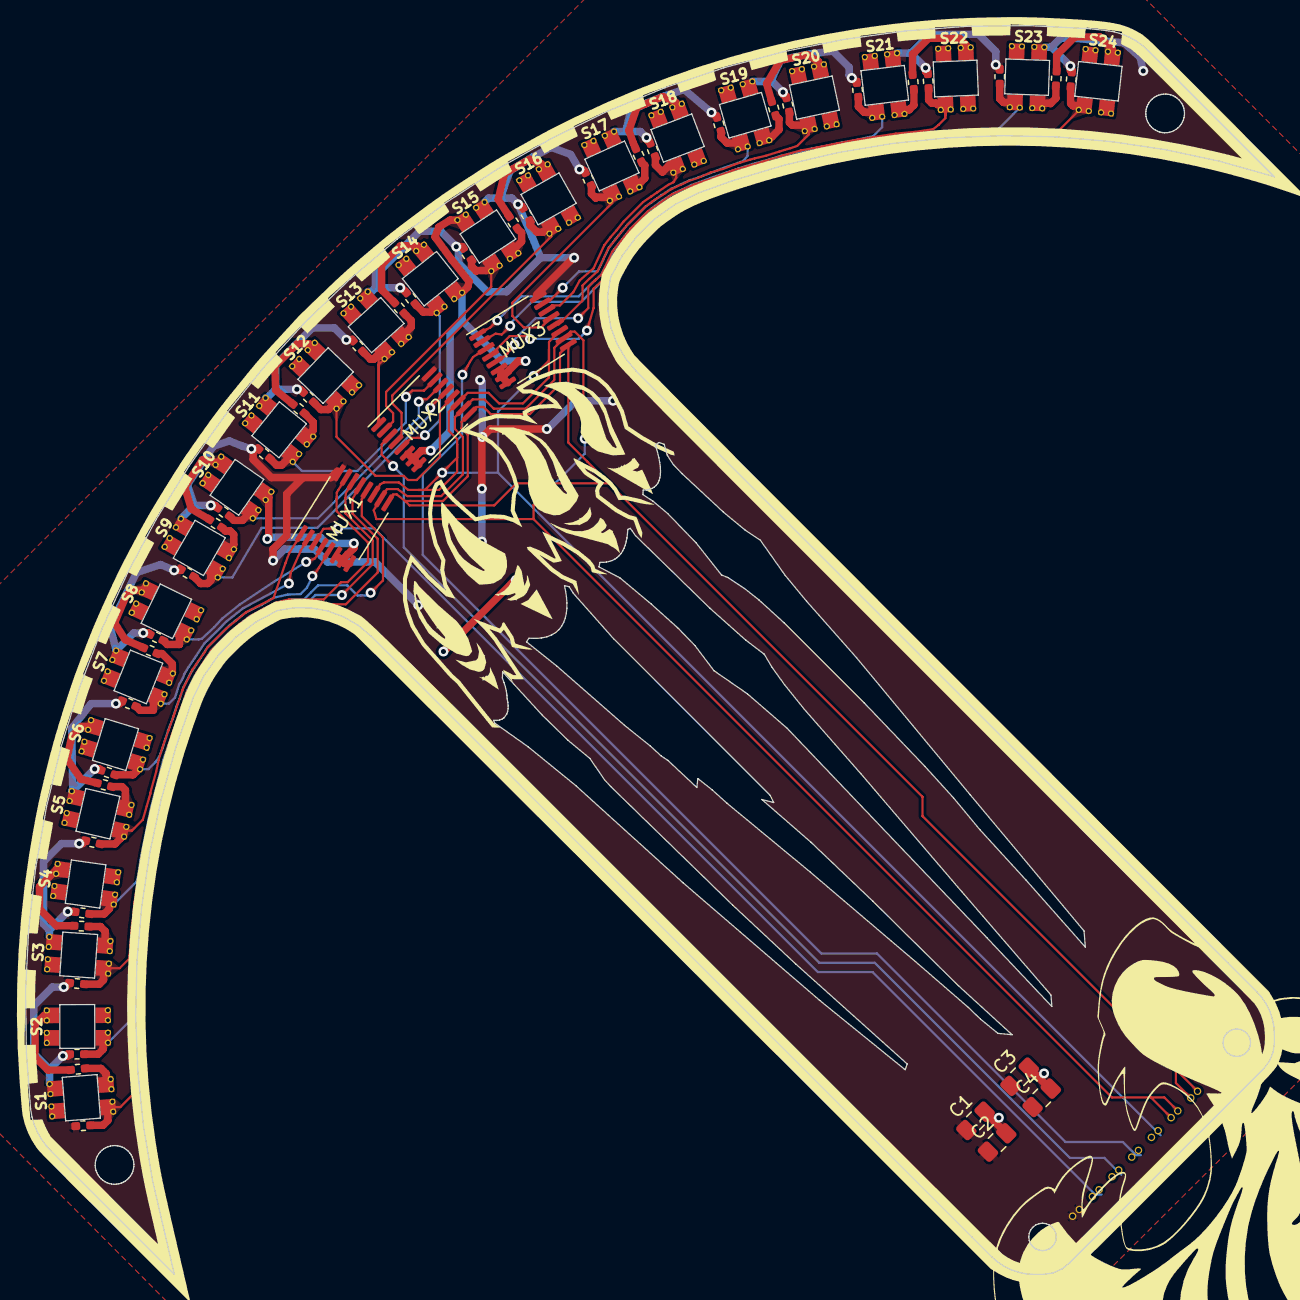
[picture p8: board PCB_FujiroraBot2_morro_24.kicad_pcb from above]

Board: 2 copper layers, 100.0 x 100.0 mm, 68 parts (1 on the bottom side), 56 nets.

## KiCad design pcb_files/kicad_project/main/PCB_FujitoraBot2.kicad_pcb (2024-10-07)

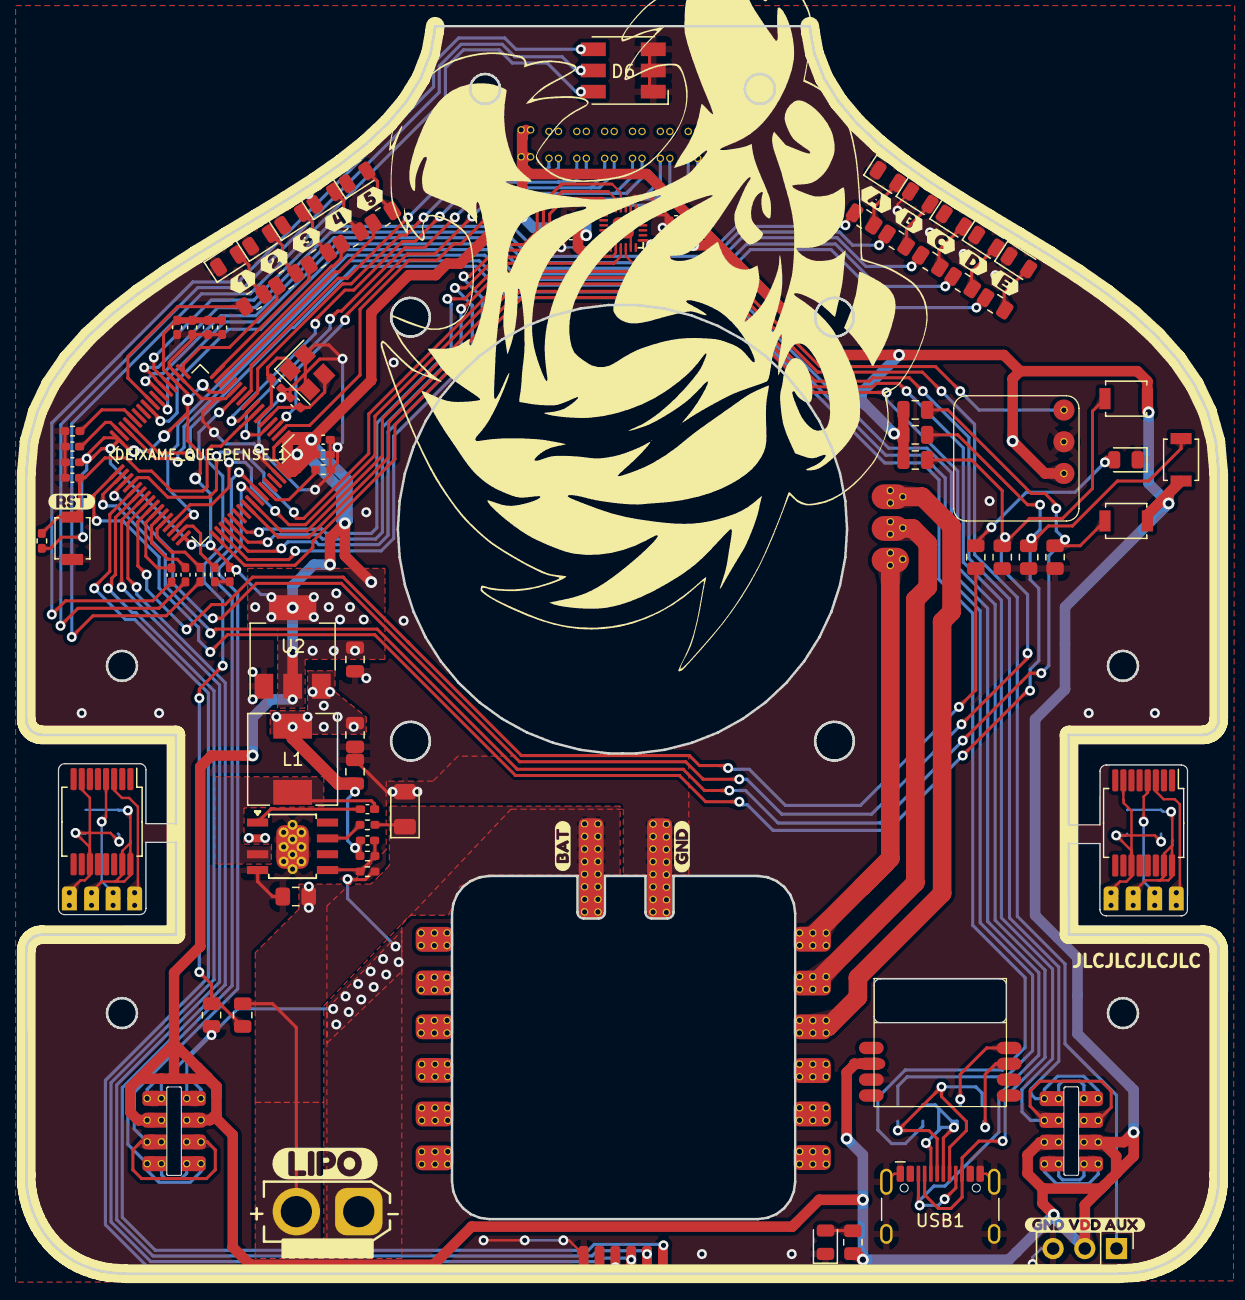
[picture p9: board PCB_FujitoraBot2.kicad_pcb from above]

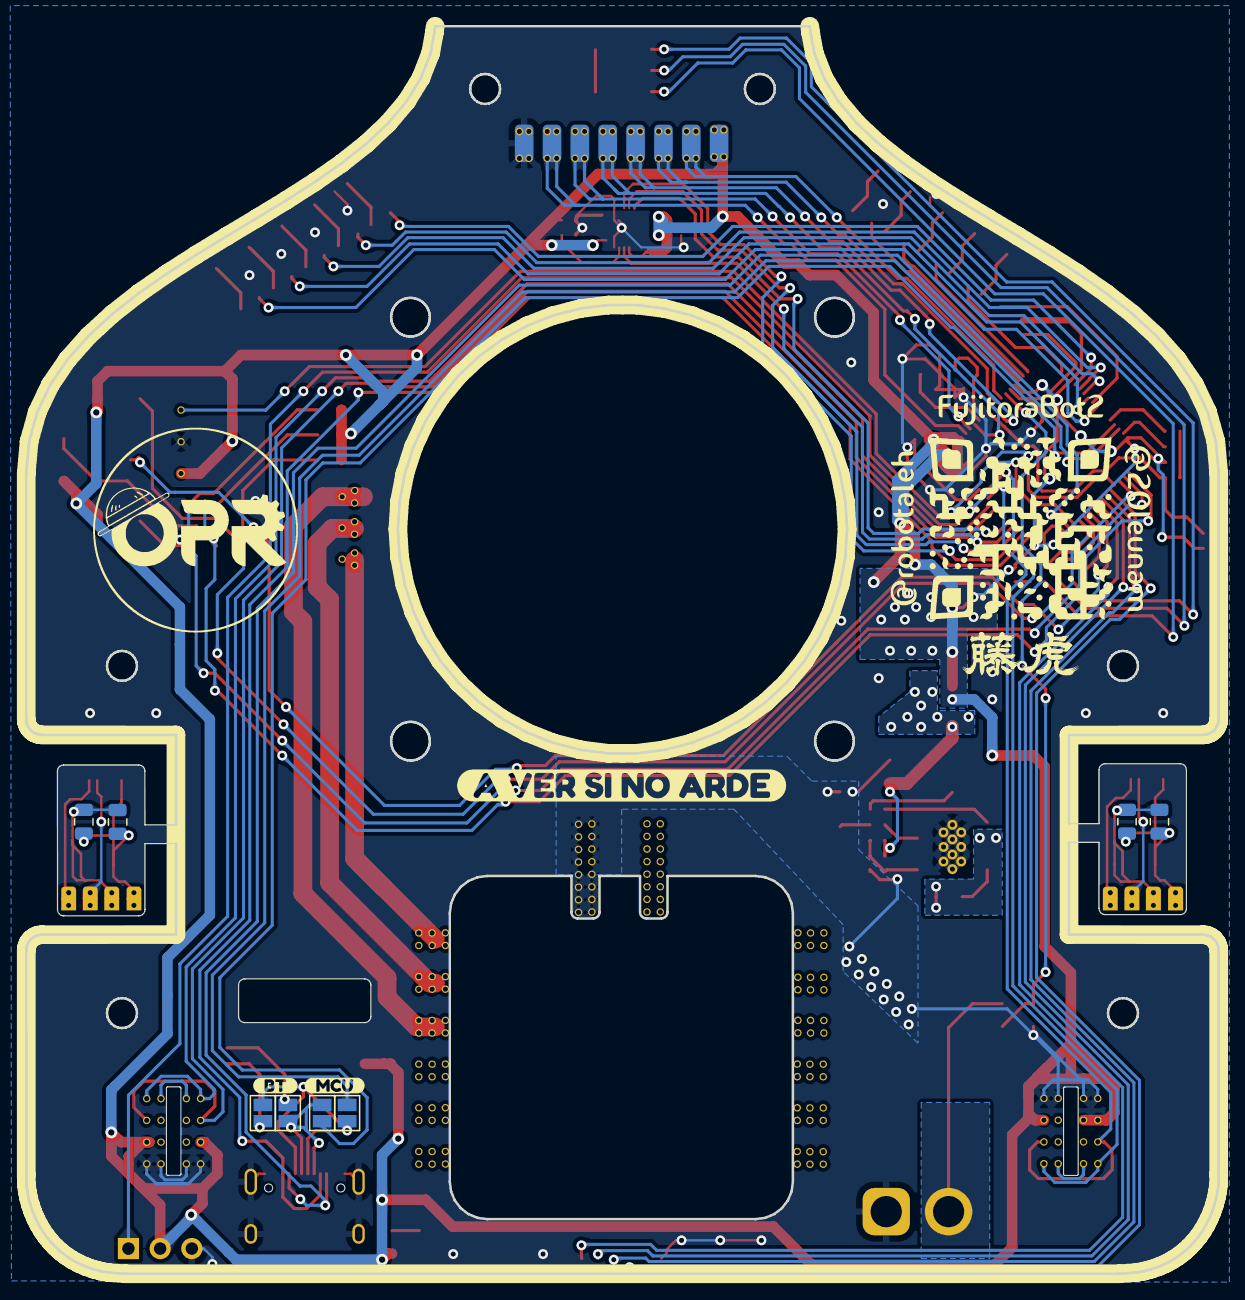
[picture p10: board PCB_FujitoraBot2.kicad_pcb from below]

Board: 2 copper layers, 95.6 x 100.0 mm, 117 parts (12 on the bottom side), 88 nets.

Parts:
BATT_1: Conn_01x02_Female; XT30 connector
BT1: Bluetooth_BLE_1x1cm
C1, C20: 4.7uF; C_0402_1005Metric_Pad0.74x0.62mm_HandSolder
C2, C3, C7, C10, C11, C15, C17: 0.1uF; C_0402_1005Metric_Pad0.74x0.62mm_HandSolder
C4, C9: 2.2uF; C_0402_1005Metric_Pad0.74x0.62mm_HandSolder
C5: 20uF; C_0402_1005Metric_Pad0.74x0.62mm_HandSolder
C6: 20pF; C_0402_1005Metric_Pad0.74x0.62mm_HandSolder
C8, C12: 1uF; C_0402_1005Metric_Pad0.74x0.62mm_HandSolder
C13, C18: 1uF; C_0805_2012Metric
C14, C19: 0.1uF; C_0805_2012Metric
C16: 0.01uF; C_0402_1005Metric_Pad0.74x0.62mm_HandSolder
CR1, CR2, CR3, CR7, CR8: 0.1uF; C_0805_2012Metric
CR4, CR5, CR9: 0.1uF; C_0402_1005Metric_Pad0.74x0.62mm_HandSolder
CR6: 0.1uF; C_0805_2012Metric_Pad1.18x1.45mm_HandSolder
CR10: 10uF; C_0805_2012Metric
D1, D2, D3, D4, D5, D7, D8, D9, D10, D11, D12, D13: LED; LED_0805_2012Metric
D6: LED_RGB; LED_RGB_5050-6
D14: D; D_1206_3216Metric
DC-DC1: SOP8_with_gnd_pad
DEIXAME_QUE_PENSE_1: STM32F405RGT6; LQFP-64_10x10mm_P0.5mm
ESC1: ESC_x4_15A; Fujitora_ESC
IC1, IC2: AS5040; SSOP-16_5.3x6.2mm_P0.65mm
J1: MORRO1; Fujitora_pads_morro
JP1, JP2, JP3, JP4: SolderJumper_2_Open; SolderJumper-2_P1.3mm_Open_Pad1.0x1.5mm
J_ENC_1, J_ENC_2: Conn_01x04_Socket; FujitoraBot2_PCBmain_Encoder
J_ENC_1_CONN1, J_ENC_2_CONN1: Conn_01x04_Pin; FujitoraBot2_PCBmodule_encoder
J_ESC1: Conn_01x06_Female; Fujitora_pads_ESC
L1: L; L_Wuerth_HCM-7050
MODULO_START_STOP1: Conn_01x03_Female; IR_Start
MOTOR_1: Conn_01x03_Female; PinHeader_1x03_P2.54mm_Vertical
PIN_AUXILIAR1: Conn_01x03_Female; PinHeader_1x03_P2.54mm_Vertical
R1, R2, R3, R4, R5, R9, R10, R11, R12, R13, R15: 330; R_0805_2012Metric
R6, R7, R8: 330; C_0402_1005Metric_Pad0.74x0.62mm_HandSolder
R14: 47k; R_0402_1005Metric_Pad0.72x0.64mm_HandSolder
R16: 1K; R_0805_2012Metric
R17, R25: 47K; R_0402_1005Metric_Pad0.72x0.64mm_HandSolder
R18, R19, R20, R23, R24: 47K; R_0805_2012Metric
R28: 45K; R_0402_1005Metric_Pad0.72x0.64mm_HandSolder
R29: 100k; R_0402_1005Metric_Pad0.72x0.64mm_HandSolder
R30: 60k; R_0402_1005Metric_Pad0.72x0.64mm_HandSolder
SW1, SW2, SW3: SW_Push; SW_SPST_B3U-1000P
SW4: SW_Reset; SW_SPST_B3U-1000P
U1: MPU-6500; FujitoraBot2_giro_MPU6500
U2: LM1117MP-3.3; SOT-223-3_TabPin2
USB1: HRO-TYPE-C-31-M-12; USB-C ST-Link USART
Y1: Crystal_GND24; Crystal_SMD_TXC_7M-4Pin_3.2x2.5mm
kibuzzard-66B8D5B6: G***; kibuzzard-66B8D5B6
kibuzzard-66B8D6B0: G***; kibuzzard-66B8D6B0
kibuzzard-66B8D59D: G***; kibuzzard-66B8D59D
kibuzzard-66B8D625: G***; kibuzzard-66B8D625
kibuzzard-66B8D672: G***; kibuzzard-66B8D672
kibuzzard-66B8D700: G***; kibuzzard-66B8D700
kibuzzard-66B8DA7F: G***; kibuzzard-66B8DA7F
kibuzzard-66B8DA98: G***; kibuzzard-66B8DA98
kibuzzard-66B8DBE7: G***; kibuzzard-66B8DBE7
kibuzzard-66B8DBFF: G***; kibuzzard-66B8DBFF
kibuzzard-66B8DC0B: G***; kibuzzard-66B8DC0B
kibuzzard-66B8DC05: G***; kibuzzard-66B8DC05
kibuzzard-66B8DC13: G***; kibuzzard-66B8DC13
kibuzzard-66B8DD07: G***; kibuzzard-66B8DD07
kibuzzard-66B8DD11: G***; kibuzzard-66B8DD11
kibuzzard-66B8DD29: G***; kibuzzard-66B8DD29
kibuzzard-66B8DD65: G***; kibuzzard-66B8DD65
kibuzzard-66B8DD76: G***; kibuzzard-66B8DD76

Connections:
+3V3: BT1.2 (VCC), C1.2, C2.2, C3.2, C7.2, C8.2, C10.2, C11.2, C12.2, C15.2, C16.2, C20.2, CR1.1, CR2.1, CR3.1, CR10.1, DEIXAME_QUE_PENSE_1.1 (VBAT), DEIXAME_QUE_PENSE_1.13 (VDDA), DEIXAME_QUE_PENSE_1.19 (VDD), DEIXAME_QUE_PENSE_1.32 (VDD), DEIXAME_QUE_PENSE_1.48 (VDD), DEIXAME_QUE_PENSE_1.64 (VDD), J1.8, J_ENC_1.2, J_ENC_2.2, MODULO_START_STOP1.1, PIN_AUXILIAR1.2, R14.2, R16.1, SW1.2, SW2.2, SW3.2, U1.8 (VDDIO), U1.13 (VDD), U2.2 (VO)
+5V: CR7.2, CR8.1, CR9.1, L1.2, R30.1, U2.3 (VI)
/ANLG_BAT: DEIXAME_QUE_PENSE_1.11 (PC3), R23.2, R24.1
/AUX: DEIXAME_QUE_PENSE_1.45 (PA12), PIN_AUXILIAR1.1
/BATT: BATT_1.2, CR6.2, D14.1 (K), DC-DC1.2 (VIN), ESC1.20 (VCC), R23.1, R29.2
/BOOT: DEIXAME_QUE_PENSE_1.60 (BOOT0), R17.1
/ENC_1_3.3: C13.1, C14.1, IC1.15 (VDD3V3), IC1.16 (VDD5V), J_ENC_1_CONN1.2
/ENC_1_A: DEIXAME_QUE_PENSE_1.59 (PB7), J_ENC_1.4
/ENC_1_A_CONN: IC1.3 (A_LSB_U), J_ENC_1_CONN1.4
/ENC_1_B: DEIXAME_QUE_PENSE_1.58 (PB6), J_ENC_1.3
/ENC_1_B_CONN: IC1.4 (B_DIR_V), J_ENC_1_CONN1.3
/ENC_1_GND: C13.2, C14.2, IC1.7 (VSS), IC1.11 (CSN), J_ENC_1_CONN1.1
/ENC_2_3.3: C18.1, C19.1, IC2.15 (VDD3V3), IC2.16 (VDD5V), J_ENC_2_CONN1.2
/ENC_2_A: DEIXAME_QUE_PENSE_1.57 (PB5), J_ENC_2.4
/ENC_2_A_CONN: IC2.3 (A_LSB_U), J_ENC_2_CONN1.4
/ENC_2_B: DEIXAME_QUE_PENSE_1.56 (PB4), J_ENC_2.3
/ENC_2_B_CONN: IC2.4 (B_DIR_V), J_ENC_2_CONN1.3
/ENC_2_GND: C18.2, C19.2, IC2.7 (VSS), IC2.11 (CSN), J_ENC_2_CONN1.1
/ESC_M1_R: ESC1.7 (M3_R), MOTOR_1.3
/ESC_M1_S: ESC1.8 (M3_S), MOTOR_1.2
/ESC_M1_T: ESC1.9 (M3_T), MOTOR_1.1
/LED_1: DEIXAME_QUE_PENSE_1.14 (PA0), R1.1
/LED_2: DEIXAME_QUE_PENSE_1.15 (PA1), R2.1
/LED_3: DEIXAME_QUE_PENSE_1.16 (PA2), R3.1
/LED_4: DEIXAME_QUE_PENSE_1.17 (PA3), R4.1
/LED_5: DEIXAME_QUE_PENSE_1.20 (PA4), R9.1
/LED_6: DEIXAME_QUE_PENSE_1.21 (PA5), R10.1
/LED_7: DEIXAME_QUE_PENSE_1.22 (PA6), R11.1
/LED_8: DEIXAME_QUE_PENSE_1.23 (PA7), R12.1
/LED_9: DEIXAME_QUE_PENSE_1.24 (PC4), R5.1
/LED_10: DEIXAME_QUE_PENSE_1.25 (PC5), R13.1
/LED_AUX: DEIXAME_QUE_PENSE_1.41 (PA8), R15.1
/MENU_ABAJO: CR2.2, DEIXAME_QUE_PENSE_1.34 (PB13), R19.1, SW2.1
/MENU_ARRIBA: CR1.2, DEIXAME_QUE_PENSE_1.35 (PB14), R18.1, SW1.1
/MENU_ENTER: CR3.2, DEIXAME_QUE_PENSE_1.33 (PB12), R20.1, SW3.1
/MUX_A: DEIXAME_QUE_PENSE_1.2 (PC13), J1.2
/MUX_B: DEIXAME_QUE_PENSE_1.3 (PC14), J1.3
/MUX_C: DEIXAME_QUE_PENSE_1.4 (PC15), J1.4
/MotorD: DEIXAME_QUE_PENSE_1.37 (PC6), J_ESC1.3
/MotorI: DEIXAME_QUE_PENSE_1.38 (PC7), J_ESC1.4
/MotorS1: DEIXAME_QUE_PENSE_1.39 (PC8), J_ESC1.5
/MotorS2: DEIXAME_QUE_PENSE_1.40 (PC9), J_ESC1.6
/RGB_B: DEIXAME_QUE_PENSE_1.44 (PA11), R6.1
/RGB_G: DEIXAME_QUE_PENSE_1.43 (PA10), R7.1
/RGB_R: DEIXAME_QUE_PENSE_1.42 (PA9), R8.1
/RST: CR4.1, DEIXAME_QUE_PENSE_1.7 (NRST), R14.1, SW4.1
/RX: JP2.2 (B), JP4.2 (B), USB1.6 (DP1), USB1.8 (DP2)
/SPI_MISO: DEIXAME_QUE_PENSE_1.52 (PC11), U1.9 (AD0/SDO)
/SPI_MOSI: DEIXAME_QUE_PENSE_1.53 (PC12), U1.24 (SDA/SDI)
/SPI_NSS: DEIXAME_QUE_PENSE_1.50 (PA15), U1.22 (nCS)
/SPI_SCK: DEIXAME_QUE_PENSE_1.51 (PC10), U1.23 (SCL/SCLK)
/START_STOP: DEIXAME_QUE_PENSE_1.36 (PB15), MODULO_START_STOP1.3
/SWCLK: DEIXAME_QUE_PENSE_1.49 (PA14), USB1.4 (CC1), USB1.10 (CC2)
/SWDIO: DEIXAME_QUE_PENSE_1.46 (PA13), USB1.3 (SBU2), USB1.9 (SBU1)
/S_DE_X8: DEIXAME_QUE_PENSE_1.10 (PC2), J1.7
/S_FR_X8: DEIXAME_QUE_PENSE_1.9 (PC1), J1.6
/S_IZ_X8: DEIXAME_QUE_PENSE_1.8 (PC0), J1.5
/TX: JP1.2 (B), JP3.1 (A), USB1.5 (DN2), USB1.7 (DN1)
GND: BATT_1.1, BT1.3 (GND), C1.1, C2.1, C3.1, C4.1, C5.1, C6.1, C7.1, C8.1, C9.1, C10.1, C11.1, C12.1, C15.1, C16.1, C17.1, C20.1, CR4.2, CR6.1, CR7.1, CR8.2, CR10.2, D1.1 (K), D2.1 (K), D3.1 (K), D4.1 (K), D5.1 (K), D6.1 (RK), D6.2 (GK), D6.3 (BK), D7.1 (K), D8.1 (K), D9.1 (K), D10.1 (K), D11.1 (K), D12.1 (K), D13.1 (K), D14.2 (A), DC-DC1.4 (GND), DC-DC1.9 (EPAD), DEIXAME_QUE_PENSE_1.12 (VSSA), DEIXAME_QUE_PENSE_1.18 (VSS), DEIXAME_QUE_PENSE_1.63 (VSS), ESC1.19 (GND), J1.1, J_ENC_1.1, J_ENC_2.1, J_ESC1.1, MODULO_START_STOP1.2, PIN_AUXILIAR1.3, R17.2, R18.2, R19.2, R20.2, R24.2, R25.2, R28.1, SW4.2, U1.11 (FSYNC), U1.18 (GND), U1.20 (RESV), U2.1 (GND), USB1.1 (GND), USB1.12 (GND), USB1.13 (SHIELD), Y1.2, Y1.4
unnamed: BT1.8 (RX), JP3.2 (B)
unnamed: BT1.7 (TX), JP4.1 (A)
unnamed: D1.2 (A), R1.2
unnamed: D2.2 (A), R2.2
unnamed: D3.2 (A), R3.2
unnamed: D4.2 (A), R4.2
unnamed: D5.2 (A), R5.2
unnamed: D6.4 (BA), R8.2
unnamed: D6.5 (GA), R7.2
unnamed: D6.6 (RA), R6.2
unnamed: D7.2 (A), R9.2
unnamed: D8.2 (A), R10.2
unnamed: D9.2 (A), R11.2
unnamed: D10.2 (A), R12.2
unnamed: D11.2 (A), R13.2
unnamed: D12.2 (A), R15.2
unnamed: D13.2 (A), R16.2
unnamed: CR5.2, DC-DC1.1 (BST)
unnamed: DC-DC1.7 (EN), R29.1
unnamed: CR9.2, DC-DC1.5 (FB), R28.2, R30.2
unnamed: CR5.1, DC-DC1.3 (SW), L1.1
unnamed: DEIXAME_QUE_PENSE_1.28 (PB2/BOOT1), R25.1
unnamed: DEIXAME_QUE_PENSE_1.29 (PB10), JP1.1 (A)
unnamed: DEIXAME_QUE_PENSE_1.30 (PB11), JP2.1 (A)
unnamed: C5.2, DEIXAME_QUE_PENSE_1.5 (PH0/OSC_IN), Y1.3
unnamed: C6.2, DEIXAME_QUE_PENSE_1.6 (PH1/OSC_OUT), Y1.1
unnamed: C9.2, DEIXAME_QUE_PENSE_1.31 (VCAP_1)
unnamed: C4.2, DEIXAME_QUE_PENSE_1.47 (VCAP_2)
unnamed: C17.2, U1.10 (REGOUT)

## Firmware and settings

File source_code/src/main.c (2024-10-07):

#include "battery.h"
#include "buttons.h"
#include "config.h"
#include "control.h"
#include "debug.h"
#include "delay.h"
#include "eeprom.h"
#include "encoders.h"
#include "leds.h"
#include "menu.h"
#include "motors.h"
#include "sensors.h"
#include "setup.h"
#include "usart.h"

static bool last_ir_start = false;

void sys_tick_handler(void) {
  clock_tick();
  update_encoder_readings();
  init_esc();
  check_buttons();
  sensors_update_line_position();
  update_gyro_readings();
  update_battery_voltage();
}

int main(void) {
  setup();
  show_battery_level();
  eeprom_load();

  sensors_calibration();

  while (1) {
    if (!is_race_started()) {
      menu_handler();
      if (check_start_run()) {
        menu_run_reset();
        last_ir_start = get_ir_start();
        configure_kinematics(menu_run_get_speed());
        set_race_started(true);
        set_RGB_color(0, 0, 0);
        set_status_led(false);
        clear_info_leds();
        uint32_t millisInicio = get_clock_ticks();
        uint16_t millisPasados = 5;
        while (get_clock_ticks() < (millisInicio + get_start_millis())) {
          millisPasados = get_clock_ticks() - millisInicio;
          uint8_t r = 0, g = 0;
          r = map(millisPasados, 0, get_start_millis(), 255, 0);
          g = map(millisPasados, 0, 1000, 0, 255);
          set_RGB_color(r, g, 0);
          if ((millisPasados > get_start_millis() * 0.75 || get_start_millis() == 0) && get_kinematics().fan_speed > 0) {
            set_target_fan_speed(get_kinematics().fan_speed / 2, 500);
          }
        }
        set_RGB_color(0, 0, 0);
        set_target_linear_speed(get_kinematics().linear_speed);
        set_target_linear_speed_percent(get_kinematics().linear_speed_percent);
        set_target_fan_speed(get_kinematics().fan_speed, 500);
        set_line_sensors_correction(true);
      }
    } else {
      if (!get_ir_start() && last_ir_start) {
        emergency_stop();
        last_ir_start = get_ir_start();
      }
      if (get_ir_start()) {
        last_ir_start = true;
      }
    }
  };
}

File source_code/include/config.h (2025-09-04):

#ifndef __CONFIG_H
#define __CONFIG_H

#include "buttons.h"

#include <stdio.h>

#define MS_CALIBRACION_LINEA 5000
#define LECTURA_MAXIMO_SENSORES_LINEA 4096
#define LECTURA_MINIMO_SENSORES_LINEA 0

// #define KP 0.045
// #define KI 0
// #define KD 2.85

// #define KP_MS 10.0
// #define KI_MS 1.2
// #define KD_MS 20.0

#define KP_LINEAR 0.00025
#define KD_LINEAR 0.00//3

#define KP_ANGULAR 0.04
#define KD_ANGULAR 0.3

#define KP_LINE_SENSORS 0.008
#define KI_LINE_SENSORS 0.00
#define KD_LINE_SENSORS 0.10

#define MILLIS_INICIO_DEBUG 2000
#define MILLIS_INICIO_RUN 5000
#define MILLIS_STOP_FAN 1500
#define TIEMPO_SIN_PISTA 150

#define MICROMETERS_PER_TICK 14.5356
#define WHEELS_SEPARATION 0.12

/** Divisor de Voltage */
#define VOLT_DIV_FACTOR 3.8673
#define BATTERY_2S_HIGH_LIMIT_VOLTAGE 7.4
#define BATTERY_2S_LOW_LIMIT_VOLTAGE 8.2
#define BATTERY_3S_HIGH_LIMIT_VOLTAGE 12.6
#define BATTERY_3S_LOW_LIMIT_VOLTAGE 11.1

#define CONFIG_RUN_RACE 1
// #define CONFIG_RUN_DEBUG 0

#define CONFIG_LINE_BLACK 0
// #define CONFIG_LINE_WHITE 1

#define ANALOG_SENSORS_MIN_PERCENT (20 / 100.0)
#define ANALOG_SENSORS_MAX_PERCENT (80 / 100.0)

uint16_t get_offtrack_time(void);
uint16_t get_start_millis(void);

#endif

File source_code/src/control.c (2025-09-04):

#include "control.h"

static bool race_started = false;
static uint32_t race_start_ms = 0;
static uint32_t race_finish_ms = 0;
static uint32_t emergency_stop_ms = 0;
static bool ir_before_start = false;

static volatile int32_t target_linear_speed = 0;
static volatile int32_t ideal_linear_speed = 0;

static volatile int32_t target_linear_speed_percent = 0;
static volatile float ideal_linear_speed_percent = 0;

static volatile float ideal_angular_speed = 0.0;

static volatile int32_t target_fan_speed = 0;
static volatile float ideal_fan_speed = 0;
static volatile float fan_speed_accel = 0;

static volatile float linear_error;
static volatile float last_linear_error;

static volatile float angular_error;
static volatile float last_angular_error;

static volatile bool mpu_correction_enabled = false;
static volatile bool line_sensors_correction_enabled = false;

static volatile float line_sensors_error;
static volatile float sum_line_sensors_error;
static volatile float last_line_sensors_error;

static volatile float voltage_left;
static volatile float voltage_right;
static volatile int32_t pwm_left;
static volatile int32_t pwm_right;

/**
 * @brief Convierte un valor de voltaje dado a su correspondiente PWM
 *
 * @param voltage
 * @return int32_t PWM a aplicar al motor
 */
static int32_t voltage_to_motor_pwm(float voltage) {
  if (voltage <= 0) { // TODO: definir un voltage mínimo de funcionamiento
    return 0;
  } else {
    return voltage / /* 12.0  */ get_battery_voltage() * (MOTORS_MAX_PWM / 2);
  }
}

static float get_measured_angular_speed(void) {
  return -get_gyro_z_radps();
}

static float get_measured_linear_speed(void) {
  return (get_encoder_left_speed() + get_encoder_right_speed()) / 2.0f;
}

static void update_ideal_linear_speed(void) {
  switch (menu_run_get_control_strategy()) {
    case CONTROL_ENCODERS:
      if (ideal_linear_speed < target_linear_speed) {
        ideal_linear_speed += get_kinematics().linear_accel / CONTROL_FREQUENCY_HZ;
        if (ideal_linear_speed > target_linear_speed) {
          ideal_linear_speed = target_linear_speed;
        }
      } else if (ideal_linear_speed > target_linear_speed) {
        ideal_linear_speed -= get_kinematics().linear_break / CONTROL_FREQUENCY_HZ;
        if (ideal_linear_speed < target_linear_speed) {
          ideal_linear_speed = target_linear_speed;
        }
      }
      break;
    case CONTROL_PWM:
      if (ideal_linear_speed_percent < target_linear_speed_percent) {
        ideal_linear_speed_percent += (float)(get_kinematics().linear_accel_percent) / CONTROL_FREQUENCY_HZ;
        if (ideal_linear_speed_percent > target_linear_speed_percent) {
          ideal_linear_speed_percent = target_linear_speed_percent;
        }
      } else if (ideal_linear_speed_percent > target_linear_speed_percent) {
        ideal_linear_speed_percent -= get_kinematics().linear_break_percent / CONTROL_FREQUENCY_HZ;
        if (ideal_linear_speed_percent < target_linear_speed_percent) {
          ideal_linear_speed_percent = target_linear_speed_percent;
        }
      }

      break;
  }
}

static void update_fan_speed(void) {
  if (ideal_fan_speed < target_fan_speed) {
    ideal_fan_speed += fan_speed_accel / CONTROL_FREQUENCY_HZ;
    if (ideal_fan_speed > target_fan_speed) {
      ideal_fan_speed = target_fan_speed;
    }
  } else if (ideal_fan_speed > target_fan_speed) {
    ideal_fan_speed -= fan_speed_accel / CONTROL_FREQUENCY_HZ;
    if (ideal_fan_speed < target_fan_speed) {
      ideal_fan_speed = target_fan_speed;
    }
  }
}

/**
 * @brief Comprueba si el robot está en funcionamiento
 *
 * @return bool
 */

bool is_race_started(void) {
  return race_started;
}

/**
 * @brief Establece el estado actual del robot
 *
 * @param state Estado actual del robot
 */

void set_race_started(bool state) {
  race_started = state;
  if (state) {
    sensors_reset_line_position();
    set_gyro_z_degrees(0);
    reset_encoder_current_angle();
    reset_control_all();
    race_start_ms = get_clock_ticks();
  } else {
    menu_reset();
    race_finish_ms = get_clock_ticks();
  }
}

uint32_t get_race_started_ms(void) {
  return race_start_ms;
}

bool check_start_run(void) {
  if (menu_run_can_start()) {
    if (get_ir_start() && !ir_before_start) {
      return true;
    } else if (get_menu_mode_btn()) {
      uint32_t ms_pressed = get_clock_ticks();
      while (get_menu_mode_btn()) {
        if (get_clock_ticks() - ms_pressed > 1000) {
          warning_status_led(25);
        }
      }
      if (get_clock_ticks() - ms_pressed > 1200) {
        return true;
      }
    }
  } else {
    ir_before_start = get_ir_start();
  }
  return false;
}

void set_mpu_correction(bool enabled) {
  mpu_correction_enabled = enabled;
}

void set_line_sensors_correction(bool enabled) {
  line_sensors_correction_enabled = enabled;
}

void reset_control_errors(void) {
  linear_error = 0;
  last_linear_error = 0;

  angular_error = 0;
  last_angular_error = 0;

  line_sensors_error = 0;
  sum_line_sensors_error = 0;
  last_line_sensors_error = 0;

  mpu_correction_enabled = false;
  line_sensors_correction_enabled = false;
}

void reset_control_speed(void) {
  target_linear_speed = 0;
  ideal_linear_speed = 0;

  target_linear_speed_percent = 0;
  ideal_linear_speed_percent = 0;

  ideal_angular_speed = 0.0;

  target_fan_speed = 0;
  ideal_fan_speed = 0;
  fan_speed_accel = 0;

  voltage_left = 0;
  voltage_right = 0;

  pwm_left = 0;
  pwm_right = 0;
}

void reset_control_all(void) {
  reset_control_errors();
  reset_control_speed();
}

void set_target_linear_speed(int32_t linear_speed) {
  target_linear_speed = linear_speed;
  if (target_linear_speed > 0 && ideal_linear_speed == 0) {
    // Velocidad lineal mínima (calculada empíricamente) para evitar cogging
    ideal_linear_speed = 165;
  }
}

int32_t get_ideal_linear_speed(void) {
  return ideal_linear_speed;
}

void set_target_linear_speed_percent(int32_t linear_speed_percent) {
  target_linear_speed_percent = linear_speed_percent;
}

void set_target_fan_speed(int32_t fan_speed, int32_t ms) {
  target_fan_speed = fan_speed;
  fan_speed_accel = (fan_speed - ideal_fan_speed) * CONTROL_FREQUENCY_HZ / ms;
}
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

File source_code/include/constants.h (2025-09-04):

#ifndef __CONSTANTS_H
#define __CONSTANTS_H

/** Constantes matemáticas */
#define PI 3.1415
#define MICROMETERS_PER_METER 1000000
#define MILLIMETERS_PER_METER 1000
#define MICROMETERS_PER_MILLIMETER 1000
#define MICROSECONDS_PER_SECOND 1000000

/** Constantes del STM32F4 */
#define SYSCLK_FREQUENCY_HZ 168000000
#define SYSTICK_FREQUENCY_HZ 1000
#define CONTROL_FREQUENCY_HZ 1000
#define LEDS_MAX_PWM 1024
#define MOTORS_MAX_PWM 1024
#define MOTORS_STOP_PWM (MOTORS_MAX_PWM / 2)
#define MOTORS_MIN_PWM ((MOTORS_MAX_PWM / 2) * 1.02)
#define ADC_RESOLUTION 4096
#define ADC_LSB (3.3 / ADC_RESOLUTION)

#endif

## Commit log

2024-09-05 Añade estructura de carpetas inicial
2024-09-05 Añade proyectos de kicad y gerbers
    [PCB_FujiroraBot2_morro_24.kicad_pcb, PCB_FujiroraBot2_morro_24.kicad_sch, PCB_FujitoraBot2.kicad_pcb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]
2024-09-05 Añade custom_libraries a los proyectos de kicad
    [bom.csv, designators.csv, positions.csv]
2024-09-06 Añade código estable de FujitoraBot (1)
2024-09-06 Añade adaptación inicial para la v2
2024-09-11 Continua la puesta en marcha de Fujitora comprobando que todo funcione individualmente
    [PCB_FujitoraBot2.kicad_sch]
2024-09-14 Actualiza los MICROMETERS_PER_TICK de los encoders
2024-09-14 Actualiza iniciación de ESC y gestión de motores
2024-09-14 Corrige función de mostrado de batería
    [battery.c]
2024-09-14 Ajusta lado y dirección de los encoders
2024-09-14 Aumenta el delay entre asignaciones de sensores
2024-09-14 Mejora gestión de botones, calibración de sensores y añade detección de tipo de LiPo
2024-09-15 Realiza adaptación general de código para primera ejecucuión correcta mediante %PWM
    [battery.c, calibrations.h, config.h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]
2024-09-18 Elimina control de intersecciones de robotracer
2024-09-18 Actualiza gestión de encoders para usar milímetros
2024-09-18 Mejora arranque y parada de ventilador de succión
2024-09-18 Actualiza, una vez más (!), el orden de los mux
2024-09-20 Mejora el control general del robot y corrige bugs para permitir reinicio de carrera sin apagar el robot
    [config.h, constants.h, control.c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]
2024-09-21 Añade cálculo de posición cartesiana a los encoders
2024-09-21 Actualiza el menú de velocidades añadiendo una extra
2024-09-21 Vuelve a actualizar el orden de los sensores (wtff?)
2024-09-21 Corrige el cálculo de la posición cartesiana del robot
    [encoders.c]
2024-09-21 Añade comprobación y aviso de linea centrada al iniciar
2024-09-25 Ajusta Ks PID linea y mejora gestión de macroarrays y reseteo de angulo de encoders en control
    [config.h, control.c, encoders.c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]
2024-09-28 Ajusta PID de sensores de línea
2024-09-28 Añade control para aplicar corrección angular solo cuando se mueva
2024-09-28 Ajusta el porcentaje de función de las kinematics
2024-09-30 Corrige orden de los macroarrays
2024-10-04 Aplica la calibración de los nuevos encoders
2024-10-04 Elimina filtro de velocidad obtenida por los encoders
2024-10-04 Elimina la parada de seguridad por tiempo (ahora se para por Mando IR)
2024-10-04 Actualiza las kinematics del modo PWM
2024-10-04 Añade log de voltage linear y angular
2024-10-04 Añade imagenes de FujitoraBot2
2024-10-07 Ajusta la velocidad de succión en modo HAKI
2024-11-20 Reduce el PWM mínimo de los motores
2024-11-20 Activa el debug por gráfica y añade batería al log
2025-02-12 Añade selección de uso de sensores en analógico o digital mediante menú
2025-02-27 Activa modo carrera (5s) y corrige fallos menores
    [config.h, control.c]
2025-09-30 Actualiza velocidades
2025-10-30 Añade control de BiggerFilter a lectura de sensores
2025-10-30 Ajusta valores de ventilador
2026-06-25 Añade documentación general y análisis de potenciales problemas
